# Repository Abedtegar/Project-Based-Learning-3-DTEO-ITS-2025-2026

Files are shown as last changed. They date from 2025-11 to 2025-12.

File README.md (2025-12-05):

# SISTEM KONTROL SEDERHANA

## Eskalator Mini Motor DC dengan Kendali ESP32 menggunakan Kontrol PID

---

### 👥 Tim Pengembang

| No | Nama | NRP |
|---|---|---|
| 1 | Abednego Tegar Imanto | 2040241044 |
| 2 | Muhammad Rifky Naufal | 2040241032 |
| 3 | Piet Avin Dutabuana | 2040241051 |
| 4 | Dhonan Rachma Dio Putra | 2040241086 |
| 5 | Luna Aulia Afifah | 2040241092 |
| 6 | Saniiyah Rif'atunnisa' | 2040241099 |

**Proyek**: CBL Semester 3 - Departemen Teknik Elektro Otomasi  
**Institusi**: Institut Teknologi Sepuluh Nopember (ITS)  
**Tahun**: 2024/2025

---

## 📋 Deskripsi Proyek

Repository ini berisi seluruh program untuk sistem kontrol escalator berbasis ESP32/ESP8266 yang dikembangkan untuk proyek CBL Semester 3. Sistem ini menggunakan arsitektur terdistribusi dengan dua board utama yang berkomunikasi melalui protokol ESP-NOW untuk kontrol motor DC (escalator) dan motor AC dengan kontrol PID real-time.

## Struktur Project

```
Program/
├── ambil_data_encoder/     # Program testing & kalibrasi encoder motor DC
├── Interface_Board/        # HMI control panel dengan LCD TFT dan encoder
├── Plant_Board/           # Controller utama motor DC/AC dengan PID
├── Tes_Interface_esp32/   # Testing dan debugging interface
├── Design_3D/             # Model 3D box, eskalator, dan interface
├── PCB_Board/             # Desain PCB Interface Board & Plant Board
└── DOKUMEN/               # Data pengukuran motor AC (CSV)
```

## Deskripsi Project

### 1. Interface_Board (HMI - Human Machine Interface)
Board interface sebagai panel kontrol dan monitoring sistem. Menggunakan LCD TFT dengan menu grafis interaktif, rotary encoder sebagai input, dan komunikasi wireless ESP-NOW.

**Platform**: ESP32 / ESP8266  
**Fitur Utama**:

#### A. Sistem Menu Navigasi
- **Main Menu**: 3 menu utama (Escalator, Motor AC, WiFi Status)
- **Escalator Menu**: 
  - Graph Mode: Real-time oscilloscope-style graph dengan buffer 100 sample
  - Control Mode: Setting PID parameters, setpoint, direction, run/stop
- **Motor AC Menu**: 
  - Graph Mode: Real-time monitoring RPM AC motor
  - Control Mode: Konfigurasi PID AC, setpoint, dan control mode
- **WiFi Menu**: Status monitoring ESP-NOW dan WiFi connection

#### B. Sistem Input (Rotary Encoder)
- **Single Click**: Select/Enter menu atau toggle edit mode
- **Double Click**: Toggle encoder direction (UP/DOWN) atau quick motor run/stop di graph mode
- **Long Press (>1 detik)**: Back/Exit ke menu sebelumnya
- **Scroll**: Navigasi menu atau edit nilai parameter (debounced)
- **Encoder Mode**: Toggle UP (increment) atau DOWN (decrement) untuk kontrol yang lebih presisi

#### C. Display & Visualisasi (LCD ST7735 128x160)
- **Grafik Real-time**: 
  - Incremental pixel rendering (oscilloscope-style) untuk efisiensi
  - Buffer 116 pixel dengan mapping ke 100 sample
  - Setpoint line (red dashed)
  - Auto-scaling untuk DC (0-115 RPM) dan AC (0-1500 RPM)
  - Error calculation dan percentage display
- **Control Screen**: Live editing PID parameters (Kp, Ki, Kd, Setpoint)
- **Status Indicators**: Motor state (RUN/STOP), connection status
- **Splash Screen**: Startup animation dengan versi info

#### D. Komunikasi ESP-NOW
- **TX Messages**: Command dan parameter ke Plant Board
  - Motor control (DC/AC run/stop)
  - PID parameters (Kp, Ki, Kd, Setpoint)
  - Direction control (FWD/REV)
  - Speed request flags
- **RX Messages**: Data monitoring dari Plant Board
  - Real-time RPM (DC & AC)
  - Timestamp untuk sinkronisasi
  - PID parameters confirmation
  - Motor status feedback
- **Tagged Float Protocol**: 8-byte frame (4-byte typeID + 4-byte float value)

#### E. Sistem Monitoring PID
- **Response Analysis**: Buffer 500 sample untuk analisis settling time
- **Timestamp Tracking**: 100-entry circular buffer untuk grid waktu
- **Error Metrics**: Perhitungan average error 50 sample terakhir
- **Percentage Error**: Error relatif terhadap setpoint

### 2. Plant_Board (Controller & Actuator)
Controller utama yang menjalankan algoritma PID dan mengendalikan motor DC (escalator) dan motor AC. Board ini bertindak sebagai "otak" sistem dengan kontrol loop tertutup.

**Platform**: ESP32  
**Fitur Utama**:

#### A. Kontrol Motor DC (Escalator)
- **PWM Control**: 12-bit resolution (0-4095), 500 Hz frequency
- **Direction Control**: Pin dedicated untuk CW/CCW
- **Encoder Quadrature**: Channel A (primary) dengan interrupt FALLING edge
- **PPR**: 14 pulses per revolution
- **Sampling Rate**: 50ms (20 Hz) dengan hardware timer
- **Speed Calculation**: RPM = (pulseCount × 60000) / (interval × PPR)
- **Gearbox Ratio**: 200:1 untuk konversi motor RPM ke output RPM

#### B. Kontrol Motor AC
- **PWM DAC Control**: 12-bit PWM untuk DAC, 8-bit output (0-255)
- **Analog Encoder**: ADC 10-bit pada GPIO32
- **Kalman Filter**: 
  - Process noise: 0.01 (tunable)
  - Measurement noise: 3.0 (tunable)
  - Mengurangi noise sensor analog untuk pembacaan RPM yang stabil
- **Scaling Factor**: 2.304147465 untuk konversi ADC ke RPM
- **Voltage Select**: Pin control untuk pemilihan tegangan DAC
- **Sampling Rate**: 10ms (100 Hz)

#### C. PID Controller (Dual Independent)
- **DC PID**:
  - Default: Kp=1.5, Ki=0.1, Kd=0.05
  - Anti-Windup: Integral clamping (±1000)
  - Anti-Stall: Minimum PWM 800 untuk mencegah motor mati
  - Output saturation: ±4095 (12-bit PWM)
  - Sample time: 50ms (sesuai encoder timer)
  
- **AC PID**:
  - Default: Kp=2.0, Ki=0.08, Kd=0.04
  - Anti-Windup: Integral clamping (±1000)
  - Anti-Stall: Minimum PWM 800
  - Output saturation: 0-255 (8-bit DAC)
  - Sample time: 10ms (sesuai encoder timer)
  
- **PID Algorithm**:
  ```
  error = setpoint - measured
  P = Kp × error
  I = Ki × Σ(error × dt)    [with clamping]
  D = Kd × (error - prev_error) / dt
  output = P + I + D        [with saturation & anti-stall]
  ```

#### D. Data Persistence (NVS Storage)
- **Preferences Library**: Non-Volatile Storage di flash ESP32
- **Stored Parameters**:
  - DC PID: Kp, Ki, Kd, Setpoint, Direction
  - AC PID: Kp, Ki, Kd, Setpoint, Voltage
- **Auto-Load**: Parameter dimuat saat startup
- **Auto-Save**: Parameter disimpan saat diterima dari Interface Board
- **Reset Function**: Clear all NVS dan restart

#### E. LED Indicators (4 LED)
- **LED_WIFI (GPIO21)**: Status komunikasi ESP-NOW (ON saat TX success)
- **LED_PID (GPIO19)**: Mode PID aktif/non-aktif
- **LED_DC_CONTROL (GPIO18)**: Motor DC running
- **LED_AC_CONTROL (GPIO5)**: Motor AC running

#### F. Hardware Timer System
- **Timer 0**: DC encoder sampling (50ms)
- **Timer 1**: AC encoder sampling (10ms)
- **ISR Safety**: portENTER_CRITICAL / portEXIT_CRITICAL untuk shared variables
- **Brownout Disable**: WRITE_PERI_REG untuk stabilitas saat PWM tinggi

#### G. Komunikasi ESP-NOW
- **WiFi Mode**: STA (Station) mode
- **MAC Filtering**: Hanya menerima dari Interface Board MAC yang terdaftar
- **Callback Functions**:
  - OnDataSent: Konfirmasi transmisi (LED feedback)
  - receiveData: Parse command dan update parameter
- **Message Types**: 32 jenis message ID (DC/AC control, PID params, etc.)

## Arsitektur Sistem

### Diagram Blok Komunikasi

```
┌──────────────────────────────────────────────────────────────────────┐
│                         INTERFACE BOARD                              │
│                       (ESP32/ESP8266 - HMI)                          │
├──────────────────────────────────────────────────────────────────────┤
│  ┌─────────────┐    ┌──────────────┐    ┌──────────────┐             │
│  │  LCD ST7735 │    │    Rotary    │    │   ESP-NOW    │             │
│  │  128x160px  │◄───┤   Encoder    │◄───┤   Protocol   │             │
│  │  Real-time  │    │  + Button    │    │   (Tagged    │             │
│  │   Graphs    │    │ (Scroll/Clk) │    │    Float)    │             │
│  └─────────────┘    └──────────────┘    └───────┬──────┘             │
│                                                 │                    │
│  Features:                                      │                    │
│  - Menu Navigation (3 levels)                   │ TX: Commands       │
│  - PID Parameter Editor                         │     Parameters     │
│  - Oscilloscope-style Graph                     │     Setpoints      │
│  - Motor Control (Run/Stop)                     │                    │
│  - Real-time Monitoring                         │ RX: RPM Data       │
└─────────────────────────────────────────────────┼────────────────────┘
                                                  │
                              ESP-NOW Wireless    │
                            (2.4GHz, <250 bytes)  │
                                                  │
┌─────────────────────────────────────────────────┼──────────────────────┐
│                          PLANT BOARD            │                      │
│                    (ESP32 - Controller)         │                      │
├─────────────────────────────────────────────────┴──────────────────────┤
│  ┌──────────────┐    ┌──────────────┐    ┌──────────────┐              │
│  │   ESP-NOW    │    │   Dual PID   │    │   Hardware   │              │
│  │   Protocol   ├───►│  Controller  ├───►│    Timers    │              │
│  │   Receiver   │    │   (DC & AC)  │    │  (50ms/10ms) │              │
│  └──────────────┘    └──────────────┘    └───────┬──────┘              │
│                                                  │                     │
│                      ┌───────────────────────────┴────────────┐        │
│                      │                                        │        │
│              ┌───────▼─────────┐                    ┌─────────▼───────┐│
│              │  DC MOTOR       │                    │   AC MOTOR      ││
│              │  + Encoder      │                    │   + Encoder     ││
│              ├─────────────────┤                    ├─────────────────┤│
│              │ - PWM 12-bit    │                    │ - PWM DAC 8-bit ││
│              │ - Quadrature    │                    │ - Analog ADC    ││
│              │ - 14 PPR        │                    │ - Kalman Filter ││
│              │ - Gearbox 200:1 │                    │ - 0-1500 RPM    ││
│              │ - 0-115 RPM out │                    │ - Voltage Sel   ││
│              │ - Direction Ctl │                    │                 ││
│              └─────────────────┘                    └─────────────────┘│
│                                                                        │
│  ┌──────────────┐    ┌──────────────┐    ┌──────────────┐              │
│  │  NVS Storage │    │  4x LED      │    │  Brownout    │              │
│  │  (PID Params)│    │  Indicators  │    │  Disable     │              │
│  └──────────────┘    └──────────────┘    └──────────────┘              │
│                                                                        │
│  Features:                                                             │
│  - Dual Independent PID (DC 50ms, AC 10ms)                             │
│  - Anti-Windup & Anti-Stall                                            │
│  - Kalman Filter untuk AC encoder                                      │
│  - Parameter Persistence (NVS Flash)                                   │
│  - Real-time Data Transmission                                         │
└────────────────────────────────────────────────────────────────────────┘
```

### Alur Komunikasi Data

**1. Startup Sequence:**
```
Plant Board:
1. Load PID parameters dari NVS Storage
2. Initialize LED indicators
3. Setup ESP-NOW (WiFi STA mode)
4. Initialize encoders (DC & AC)
5. Start PWM timers
6. Start hardware timers (50ms DC, 10ms AC)
7. Send parameter confirmation ke Interface

Interface Board:
1. Initialize LCD ST7735
2. Initialize rotary encoder + button
3. Setup ESP-NOW
4. Show splash screen (2 detik)
5. Load main menu
6. Request Plant Board restart (sync)
```

**2. Real-time Control Loop:**
```
Interface Board (Main Loop ~10ms):
1. Read encoder position (interrupt-based)
2. Detect button clicks (single/double/long)
3. Update menu state (navigate/edit/select)
4. Send commands via ESP-NOW (jika ada perubahan)
5. Receive RPM data dari Plant
6. Update display (incremental rendering)

Plant Board (Timer ISR):
DC Timer (50ms):
  1. Calculate pulse count
  2. Compute RPM = (pulseCount × 60000) / (50 × 14)
  3. Apply gearbox ratio (÷200)
  4. Run PID if enabled
  5. Set PWM output
  6. Send data via ESP-NOW

AC Timer (10ms):
  1. Read ADC value
  2. Apply Kalman filter
  3. Compute RPM = ADC × 2.304147465
  4. Run PID if enabled
  5. Set DAC output
  6. Send data via ESP-NOW
```

**3. PID Control Flow:**
```
┌─────────────────────────────────────────────────────────────┐
│                     PID CONTROL LOOP                        │
├─────────────────────────────────────────────────────────────┤
│  1. Read Setpoint (dari Interface Board)                    │
│  2. Read Current RPM (dari Encoder)                         │
│  3. Calculate Error = Setpoint - Current                    │
│  4. Calculate P = Kp × Error                                │
│  5. Calculate I = Ki × Σ(Error × dt)  [Anti-Windup]         │
│  6. Calculate D = Kd × (Error - PrevError) / dt             │
│  7. Output = P + I + D                                      │
│  8. Apply Saturation (0-4095 DC, 0-255 AC)                  │
│  9. Apply Anti-Stall (minimum PWM 800)                      │
│ 10. Write to PWM/DAC                                        │
│ 11. Store PrevError                                         │
│ 12. Send RPM & Error ke Interface                           │
└─────────────────────────────────────────────────────────────┘
```

**4. ESP-NOW Message Protocol:**
```
Frame Format: [TypeID: 4 bytes][Value: 4 bytes] = 8 bytes total

Message Types (Interface → Plant):
- MSG_DC_KP (11): Kp untuk DC PID
- MSG_DC_KI (12): Ki untuk DC PID
- MSG_DC_KD (13): Kd untuk DC PID
- MSG_DC_Setpoint (14): Target RPM DC motor
- MSG_DC_Control (15): Run/Stop DC motor (1/0)
- MSG_DC_Direction (16): Direction FWD/REV (0/1)
- MSG_AC_KP (21): Kp untuk AC PID
- MSG_AC_KI (22): Ki untuk AC PID
- MSG_AC_KD (23): Kd untuk AC PID
- MSG_AC_Setpoint (24): Target RPM AC motor
- MSG_AC_Control (25): Run/Stop AC motor (1/0)
- MSG_AC_Voltage (26): Voltage selection
- MSG_PID_MODE (30): Enable/Disable PID (1/0)
- MSG_SPD_REQUEST (31): Request speed data (1=DC, 2=AC, 0=off)
- ESP_RESTART (100): Restart Plant Board

Message Types (Plant → Interface):
- MSG_DC_SPEED (10): Current RPM DC motor
- MSG_AC_SPEED (20): Current RPM AC motor
- MSG_TIMESTAMP (32): Timestamp untuk sinkronisasi
- MSG_DC_KP/KI/KD: Confirmation parameter diterima
- MSG_AC_KP/KI/KD: Confirmation parameter diterima
```

## Requirements

### Hardware
- ESP32 Development Board 
- ESP8266 NodeMCU (opsional, untuk Interface)
- LCD ST7735 TFT Display (128x160)
- Rotary Encoder dengan push button
- Motor DC dengan encoder
- Motor AC (opsional)
- Motor Driver

### Software
- [PlatformIO](https://platformio.org/)
- VS Code dengan PlatformIO extension
- Driver CH340/CP2102 (untuk ESP32/ESP8266)

### Libraries
- Adafruit GFX Library
- Adafruit ST7735 Library
- ESP-NOW (built-in)
- WiFi (built-in)

## Quick Start

### 1. Install PlatformIO
```bash
# Install PlatformIO CLI atau gunakan VS Code extension
pip install platformio
```

### 2. Clone/Download Repository
```bash
cd "d:\Kuliah\ITS\SMT3\CBL\Program"
```

### 3. Build & Upload

#### Plant Board (Upload pertama)
```bash
cd Plant_Board
platformio run --target upload
platformio device monitor
# Catat MAC address yang muncul di serial monitor
```

#### Interface Board
```bash
cd Interface_Board
# Edit include/PinConfig.h, sesuaikan PLANT_MAC dengan MAC Plant Board
platformio run --target upload
platformio device monitor
```

## Konfigurasi Detail

### 1. Plant Board Configuration

**File: `Plant_Board/include/PlantConfig.h`**

#### A. Pin Configuration

```cpp
// DC Motor Control
#define MOTOR_PWM_PIN 13        // PWM output ke motor driver
#define MOTOR_DIR_PIN 23        // Direction control (CW/CCW)
#define PWM_CHANNEL 0           // LEDC channel
#define PWM_FREQ 500            // 500 Hz PWM frequency
#define PWM_RESOLUTION 12       // 12-bit (0-4095)

// DC Motor Encoder
#define ENCODER_A_PIN 34        // Channel A (primary interrupt)
#define ENCODER_B_PIN 35        // Channel B (direction detection)
#define PPR 14                  // Pulses Per Revolution
#define DCREAD_INTERVAL 50      // Sampling interval 50ms

// AC Motor Control
#define AC_DAC1_PIN 25          // DAC output 1
#define AC_DAC2_PIN 26          // DAC output 2
#define AC_DAC_SOURCE_PIN 27    // Source selection
#define AC_DAC_VOLTAGE_SELECT_PIN 12  // Voltage level selection
#define ACPWM_CHANNEL 1         // LEDC channel untuk DAC
#define ACPWM_FREQ 500          // PWM frequency
#define ACPWM_RESOLUTION 12     // 12-bit resolution

// AC Motor Encoder
#define AC_ENCODER_PIN 32       // Analog input (ADC)
#define ACREAD_INTERVAL 10      // Sampling interval 10ms
#define AC_READ_SCALING_FACTOR 2.304147465f  // ADC to RPM conversion

// LED Indicators
#define LED_WIFI 21             // ESP-NOW communication status
#define LED_PID 19              // PID mode active
#define LED_DC_CONTROL 18       // DC motor running
#define LED_AC_CONTROL 5        // AC motor running
```

#### B. Network Configuration

```cpp
// MAC Address Interface Board (dapatkan dari Serial Monitor Interface)
static const uint8_t INTERFACE_MAC[] = {
    0x50, 0x02, 0x91, 0x78, 0x72, 0xA7  // SESUAIKAN DENGAN MAC ANDA
};

// Data transmission interval
#define DATA_SEND_INTERVAL 1000  // Kirim data setiap 1000ms
```

#### C. PID Tuning Parameters

**File: `Plant_Board/src/PID.cpp`**

```cpp
// DC Motor PID (Escalator)
volatile float DCkP = 1.5f;      // Proportional gain
volatile float DCkI = 0.1f;      // Integral gain
volatile float DCkD = 0.05f;     // Derivative gain
volatile float DCsetpoint = 50.0f;  // Target RPM (output shaft)

// AC Motor PID
volatile float ACkP = 2.0f;      // Proportional gain
volatile float ACkI = 0.08f;     // Integral gain
volatile float ACkD = 0.04f;     // Derivative gain
volatile float ACsetpoint = 0.0f;   // Target RPM

// Anti-Windup Limits
#define DC_INTEGRAL_MAX 1000.0   // Max integral accumulation
#define DC_INTEGRAL_MIN -1000.0
#define AC_INTEGRAL_MAX 1000.0
#define AC_INTEGRAL_MIN -1000.0

// Anti-Stall Minimum PWM
#define DC_PWM_MIN 800.0f        // Minimum PWM untuk mencegah stall
#define AC_PWM_MIN 800.0f
```

#### D. Kalman Filter Tuning (AC Motor)

**File: `Plant_Board/src/Plant.cpp`**

```cpp
// Kalman Filter Parameters
float AC_process_noise = 0.01;   // Process noise covariance (Q)
float AC_error_measure = 4.0;    // Measurement noise covariance (R)

// Adjust di setup():
ACsetKalmanParams(0.01, 3.0);   // (process_noise, measure_noise)
// - Turunkan process_noise untuk response lebih lambat tapi smooth
// - Turunkan measure_noise jika sensor akurat
```

### 2. Interface Board Configuration

**File: `Interface_Board/include/PinConfig.h`**

#### A. Pin Configuration (ESP32)

```cpp
// LCD ST7735 (SPI)
#define TFT_CS 15               // Chip Select
#define TFT_RST 4               // Reset
#define TFT_DC 5                // Data/Command
// Hardware SPI: MOSI=23, SCK=18

// Rotary Encoder
#define ENCODER_CLK 27          // Clock (Channel A) - NOT USED in interrupt
#define ENCODER_DT 26           // Data (Channel B) - PRIMARY interrupt
#define ENCODER_SW 25           // Switch button (polling)
```

#### B. Pin Configuration (ESP8266)

```cpp
// LCD ST7735 (SPI)
#define TFT_CS 15               // GPIO15
#define TFT_RST 4               // GPIO4
#define TFT_DC 5                // GPIO5
// Hardware SPI: MOSI=GPIO13, SCK=GPIO14

// Rotary Encoder
#define ENCODER_CLK 12          // GPIO12
#define ENCODER_DT 2            // GPIO2 - PRIMARY interrupt
#define ENCODER_SW 16           // GPIO16
```

#### C. Network Configuration

```cpp
// WiFi AP (Optional - currently not used)
#define WIFI_AP_SSID "GameBoard_AP"
#define WIFI_AP_PASSWORD "12345678"

// MAC Address Plant Board (dapatkan dari Serial Monitor Plant)
static const uint8_t PLANT_MAC[6] = {
    0x7C, 0x9E, 0xBD, 0x48, 0x85, 0xB4  // SESUAIKAN DENGAN MAC ANDA
};
```

#### D. Display Configuration

**File: `Interface_Board/src/src/ControlMenuSystem_simple.cpp`**

```cpp
// Graph Scaling
constexpr float ESC_GRAPH_MAX = 115.0f;   // Max RPM DC (output shaft)
constexpr float AC_GRAPH_MAX = 1500.0f;   // Max RPM AC

// History Buffer
#define MAX_SAMPLES 100          // Jumlah sample dalam buffer
#define GRAPH_WIDTH 116          // Pixel width grafik

// Timing
#define DEBOUNCE_TIME 50         // Button debounce (ms)
#define LONG_PRESS_TIME 1000     // Long press detection (ms)
#define DOUBLE_CLICK_TIME 400    // Double click window (ms)
```

### 3. Cara Mendapatkan MAC Address

#### Plant Board:

```bash
cd Plant_Board
platformio device monitor -b 115200
```

Output akan menampilkan:
```
=== PLANT BOARD STARTUP ===
ESP-NOW MAC Address: 7C:9E:BD:48:85:B4
```

Salin MAC address ini ke `Interface_Board/include/PinConfig.h`

#### Interface Board:

```bash
cd Interface_Board
platformio device monitor -b 115200
```

Output akan menampilkan MAC address ESP8266/ESP32.
Salin ke `Plant_Board/include/PlantConfig.h`

### 4. PID Tuning Guide

#### Metode Ziegler-Nichols (Manual Tuning)

1. **Set Ki = 0, Kd = 0**
2. **Naikkan Kp** hingga sistem oscillate (bergetar stabil)
3. **Catat Ku (Kp critical)** dan **Tu (periode oscillasi)**
4. **Hitung parameter**:
   - Kp = 0.6 × Ku
   - Ki = 1.2 × Ku / Tu
   - Kd = 0.075 × Ku × Tu

#### Fine Tuning:

**Kp (Proportional)**:
- Terlalu kecil: Response lambat, steady-state error besar
- Terlalu besar: Overshoot, oscillation
- Optimal: Response cepat tanpa overshoot berlebih

**Ki (Integral)**:
- Terlalu kecil: Steady-state error tidak hilang
- Terlalu besar: Integral windup, slow settling
- Optimal: Eliminasi steady-state error dalam waktu wajar

**Kd (Derivative)**:
- Terlalu kecil: Overshoot besar
- Terlalu besar: Noise amplification, sistem tidak stabil
- Optimal: Damping overshoot tanpa noise berlebih

#### Tuning Melalui Interface:

1. Pilih menu **Escalator** atau **Motor AC**
2. Pilih **Control** (single click di graph mode)
3. Navigate ke parameter yang ingin diedit
4. Single click untuk enter edit mode
5. Putar encoder untuk adjust nilai
6. Single click lagi untuk save & transmit ke Plant

## Testing

### Test Encoder
```bash
cd Tes_Interface_esp32
platformio run --target upload
platformio device monitor
# Putar encoder dan lihat output
```

### Test Komunikasi ESP-NOW
1. Upload Plant_Board
2. Upload Interface_Board
3. Monitor serial pada kedua board
4. Cek status ESP-NOW di menu Interface

## Troubleshooting

### 1. ESP-NOW Tidak Terkoneksi

**Gejala:**
- LED_WIFI pada Plant Board tidak menyala
- Status ESP-NOW di menu WiFi menampilkan "FAIL"
- Tidak ada data RPM yang diterima Interface Board

**Solusi:**

A. **Verifikasi MAC Address**
```bash
# Plant Board
platformio device monitor -b 115200
# Lihat output: "ESP-NOW MAC Address: XX:XX:XX:XX:XX:XX"

# Pastikan MAC ini sama dengan yang di Interface_Board/include/PinConfig.h
```

B. **Cek WiFi Mode**
```cpp
// Plant Board: WiFi.mode(WIFI_STA) - harus STA mode
// Interface Board: WiFi.mode(WIFI_STA) atau WIFI_AP_STA
```

C. **Restart Sequence**
1. Upload Plant Board → tunggu hingga "ESP-NOW siap"
2. Upload Interface Board → auto send restart command
3. Monitor Serial kedua board untuk konfirmasi

D. **Cek Channel WiFi**
- ESP-NOW harus di channel yang sama (default: 0 = auto)
- Jika ada WiFi router nearby, bisa conflict

**Debug Command:**
```cpp
// Tambahkan di Plant_Board/src/PlantESPNow.cpp
Serial.print("Peer add result: ");
Serial.println(esp_now_add_peer(&peerInfo));  // Harus return 0 (ESP_OK)
```

### 2. Encoder Tidak Terbaca / Count Tidak Akurat

**Gejala:**
- RPM selalu 0 atau tidak berubah
- Count encoder tidak increment saat motor berputar
- Arah putaran terbalik

**Solusi:**

A. **Cek Koneksi Hardware**
```
Encoder Pin:
- Channel A (CLK) → ESP32 GPIO34/35 (input only pins)
- Channel B (DT)  → ESP32 GPIO35/34
- VCC → 3.3V (JANGAN 5V!)
- GND → GND
- Pull-up resistor: 10kΩ ke VCC (jika encoder tidak ada internal pull-up)
```

B. **Test Encoder Standalone**
```bash
cd ambil_data_encoder
platformio run --target upload
platformio device monitor

# Putar encoder manual, lihat output count
```

C. **Verifikasi Interrupt**
```cpp
// Interface Board: Hanya attach ENCODER_DT dengan FALLING edge
attachInterrupt(digitalPinToInterrupt(ENCODER_DT), DChandleEncoder, FALLING);
// JANGAN attach CLK untuk mencegah double trigger

// Plant Board: Attach ENCODER_A_PIN dengan CHANGE
attachInterrupt(digitalPinToInterrupt(ENCODER_A_PIN), DChandleEncoderA, CHANGE);
```

D. **Direction Terbalik**
- Swap Channel A dan B di konfigurasi
- Atau toggle `DCDirection` di logika

E. **Noise / Bouncing**
- Tambahkan capacitor 100nF antara setiap pin encoder dan GND
- Kurangi panjang kabel encoder
- Gunakan shielded cable untuk encoder

### 3. LCD Tidak Menyala / Blank Screen

**Gejala:**
- LCD putih atau blank setelah power on
- Backlight nyala tapi tidak ada gambar
- Splash screen tidak muncul

**Solusi:**

A. **Cek Koneksi SPI**
```
LCD ST7735 Pin → ESP32/ESP8266:
- VCC → 3.3V atau 5V (sesuai spesifikasi LCD)
- GND → GND
- CS  → GPIO15 (TFT_CS)
- RST → GPIO4 (TFT_RST)
- DC  → GPIO5 (TFT_DC)
- MOSI → GPIO23 (ESP32) atau GPIO13 (ESP8266)
- SCK → GPIO18 (ESP32) atau GPIO14 (ESP8266)
- LED → 3.3V (backlight)
```

B. **Test Koneksi dengan Multimeter**
- Cek continuity dari ESP pin ke LCD pin
- Cek tegangan VCC = 3.3V atau 5V
- Cek GND tidak short dengan VCC

C. **Manual Reset LCD**
```cpp
// Tambahkan di setup() sebelum tft.initR()
digitalWrite(TFT_RST, LOW);
delay(100);
digitalWrite(TFT_RST, HIGH);
delay(100);
```

D. **Cek Inisialisasi LCD**
```cpp
// Ganti INITR_BLACKTAB dengan yang lain jika blank
tft.initR(INITR_BLACKTAB);   // Coba: INITR_GREENTAB, INITR_REDTAB
tft.setRotation(0);           // Coba: 0, 1, 2, 3
```

E. **Power Supply Tidak Cukup**
- LCD butuh ~50-100mA saat backlight ON
- Gunakan power supply minimal 500mA
- Jangan powered dari USB komputer yang lemah

### 4. PID Tidak Stabil / Oscillating

**Gejala:**
- Motor bergetar (hunting)
- RPM overshoot berlebihan
- Tidak bisa mencapai setpoint

**Solusi:**

A. **Tuning PID Terlalu Agresif**
```cpp
// Mulai dari konservatif:
DCkP = 0.5;   // Kurangi Kp hingga oscillation hilang
DCkI = 0.01;  // Mulai dari Ki sangat kecil
DCkD = 0.0;   // Set Kd = 0 dulu

// Naikkan Kp bertahap hingga response cepat tapi tidak oscillate
// Tambahkan Ki untuk eliminasi steady-state error
// Tambahkan Kd jika masih overshoot
```

B. **Anti-Windup Tidak Efektif**
```cpp
// Pastikan integral clamping aktif
if (DCintegralSum > DC_INTEGRAL_MAX)
    DCintegralSum = DC_INTEGRAL_MAX;
else if (DCintegralSum < DC_INTEGRAL_MIN)
    DCintegralSum = DC_INTEGRAL_MIN;
```

C. **Sampling Rate Terlalu Lambat**
- DC: 50ms (20 Hz) - OK untuk most applications
- AC: 10ms (100 Hz) - Bisa turunkan jika masih oscillate
- Semakin cepat motor, perlu sampling rate lebih tinggi

D. **Motor Stall (Anti-Stall Aktif Terlalu Sering)**
```cpp
// Turunkan DC_PWM_MIN jika motor sering "jump"
#define DC_PWM_MIN 600.0f  // Default 800, coba turunkan
```

E. **Mechanical Load Berubah**
- PID tuning valid untuk specific load
- Jika load berubah drastis, perlu re-tune atau adaptive PID

### 5. Motor Tidak Berputar / Stuck

**Gejala:**
- PWM output sudah benar tapi motor diam
- Motor bergetar tapi tidak rotate
- Motor berputar hanya di PWM tinggi

**Solusi:**

A. **Cek Motor Driver**
```
Driver Pin:
- PWM signal OK? (cek dengan oscilloscope atau LED)
- Direction signal OK?
- Enable pin HIGH?
- Power supply driver cukup? (minimal 1A untuk motor kecil)
```

B. **Cek Power Supply Motor**
- Tegangan motor sesuai rating (6V, 12V, 24V, etc.)
- Current rating cukup (motor butuh 2-5A saat start)
- Cek voltage drop saat motor start

C. **PWM Frequency Terlalu Rendah/Tinggi**
```cpp
// Coba adjust PWM frequency
#define PWM_FREQ 500   // Default, coba 1000 atau 20000
```

D. **Dead Zone / Starting Torque**
```cpp
// Motor perlu minimum PWM untuk overcome starting torque
#define DC_PWM_MIN 1000.0f  // Naikkan dari 800
```

E. **Motor Rusak / Bearing Macet**
- Coba putar motor manual → harus smooth
- Cek dengan multimeter: resistance coil motor normal

### 6. Data Serial Monitor Corrupt / Tidak Terbaca

**Gejala:**
- Character acak di serial monitor
- Data tidak lengkap atau putus-putus

**Solusi:**

A. **Cek Baud Rate**
```bash
# Pastikan 115200 di semua board
platformio device monitor -b 115200
```

B. **Driver USB-Serial**
- Install driver CH340 atau CP2102
- Windows: Device Manager → Ports → update driver
- Linux: `sudo usermod -a -G dialout $USER` (logout-login)

C. **Kabel USB Rusak**
- Ganti dengan kabel USB yang bagus (data + power)
- Jangan gunakan charging-only cable

D. **Buffer Overflow**
```cpp
// Kurangi Serial.print() di dalam ISR
// Gunakan flag dan print di main loop
```

### 7. ESP32 Brownout / Restart Terus

**Gejala:**
- ESP32 restart sendiri saat motor start
- Serial output: "Brownout detector was triggered"

**Solusi:**

A. **Disable Brownout Detector** (temporary)
```cpp
// Di setup() Plant_Board
#include "soc/soc.h"
#include "soc/rtc_cntl_reg.h"
WRITE_PERI_REG(RTC_CNTL_BROWN_OUT_REG, 0);
```

B. **Power Supply Tidak Cukup** (root cause)
- ESP32 butuh minimal 500mA
- Motor + ESP32 total bisa 3-5A
- JANGAN powered motor dari ESP32 VCC
- Gunakan power supply terpisah untuk motor dan ESP32
- Common ground antara power supply motor dan ESP32

C. **Decoupling Capacitor**
- Tambahkan 100µF capacitor di VCC ESP32
- Tambahkan 0.1µF ceramic capacitor di setiap VCC pin

### 8. Kalman Filter AC Motor Tidak Smooth

**Gejala:**
- RPM AC masih noisy
- Filter tidak efektif

**Solusi:**

A. **Tuning Parameter Kalman**
```cpp
// Naikkan measurement noise jika sensor sangat noisy
ACsetKalmanParams(0.01, 5.0);  // process_noise, measure_noise

// Turunkan process noise untuk smoother tapi slower response
ACsetKalmanParams(0.005, 3.0);
```

B. **Moving Average Tambahan**
```cpp
// Tambahkan simple moving average sebelum Kalman
#define MA_SIZE 5
float ma_buffer[MA_SIZE];
float ma_sum = 0;
int ma_index = 0;

// Update buffer
ma_sum -= ma_buffer[ma_index];
ma_buffer[ma_index] = raw_rpm;
ma_sum += raw_rpm;
ma_index = (ma_index + 1) % MA_SIZE;
float filtered = ma_sum / MA_SIZE;
```

C. **Hardware Filter**
- Tambahkan RC filter di output sensor analog
- R = 10kΩ, C = 100nF → cutoff ~160 Hz

## Serial Monitor

Baud rate untuk semua project: **115200**

```bash
# Monitor dengan PlatformIO
platformio device monitor -b 115200

# Atau gunakan serial monitor lain
# Arduino IDE, PuTTY, dll.
```

## Advanced Features & Technical Details

### 1. Real-time Graph Rendering (Oscilloscope-Style)

Interface Board menggunakan teknik **incremental pixel rendering** untuk update grafik secara efisien tanpa full redraw.

**Algoritma:**
```cpp
// Buffer Y-position untuk setiap kolom pixel (116 kolom)
static int escGraphY[116];

// Setiap data baru masuk:
1. Shift buffer kanan ke kiri (escGraphY[i] = escGraphY[i-1])
2. Hapus pixel lama di posisi yang berubah
3. Gambar pixel baru di posisi baru
4. Update setpoint line (red dashed)
5. Update metrics (speed, error, percent error)

// Hasil: Smooth scrolling graph tanpa flicker
```

**Metrics Calculation:**
- **Current Speed**: Nilai RPM terbaru dari Plant Board
- **Setpoint**: Target RPM (red line)
- **Error**: `Current - Setpoint`
- **Percent Error**: Average absolute error 50 sample terakhir / setpoint × 100%

### 2. Encoder Quadrature Decoding

**Plant Board (DC Motor):**
```cpp
// Single-edge interrupt pada Channel A dengan pembacaan Channel B
void IRAM_ATTR DChandleEncoderA() {
    int stateA = digitalRead(ENCODER_A_PIN);
    int stateB = digitalRead(ENCODER_B_PIN);
    
    if (stateA == HIGH) {
        if (stateB == LOW) DCencoder++;  // CW rotation
        else DCencoder--;                 // CCW rotation
    } else {
        if (stateB == HIGH) DCencoder++;
        else DCencoder--;
    }
}

// Keuntungan: 
// - Deteksi arah otomatis
// - Resolution 4x (jika attach kedua channel)
// - Debouncing hardware dengan interrupt CHANGE
```

**Interface Board (Rotary Encoder):**
```cpp
// Mode-based increment/decrement
if (encoderMode == ENCODER_UP) {
    DCencoder++;   // Increment mode
} else {
    DCencoder--;   // Decrement mode
}

// Keuntungan:
// - User bisa toggle arah scroll
// - Lebih intuitif untuk menu navigation
// - Single interrupt pada DT pin (less noise)
```

### 3. ESP-NOW Protocol Efficiency

**Frame Structure:**
```
Byte 0-3: TypeID (int32_t)  → Identifier jenis data
Byte 4-7: Value (float)      → Payload data

Total: 8 bytes per message
```

**Keuntungan:**
- **Compact**: Hanya 8 bytes (vs JSON ~50-100 bytes)
- **Fast**: Parsing langsung dengan memcpy, no string parsing
- **Type-safe**: TypeID mencegah misinterpretation
- **Scalable**: Mudah tambah message type baru

**Latency Analysis:**
- ESP-NOW TX time: ~1-2ms
- Processing time: <1ms
- Total latency: <5ms (real-time control)

### 4. NVS Storage Implementation

**Persistence Layer:**
```cpp
Preferences preferences;

// Save (Plant Board)
preferences.begin("plant_config", false);  // namespace
preferences.putFloat("dc_kp", DCkP);
preferences.putFloat("dc_ki", DCkI);
// ... dst

// Load (Plant Board startup)
DCkP = preferences.getFloat("dc_kp", 1.5f);  // default 1.5
DCkI = preferences.getFloat("dc_ki", 0.1f);
```

**Benefits:**
- **Non-volatile**: Parameter tersimpan meski power off
- **Fast**: Flash read <1ms
- **Reliable**: Wear leveling otomatis oleh ESP32
- **Simple API**: Key-value store seperti database

**Use Case:**
1. User tuning PID via Interface Board
2. Interface send parameter ke Plant Board
3. Plant Board auto-save ke NVS
4. Next power-on: Load parameter terakhir

### 5. Kalman Filter Implementation (AC Motor)

**Algorithm:**
```cpp
// Prediction step
predicted_estimate = estimate;
predicted_error = error_estimate + process_noise;

// Update step
kalman_gain = predicted_error / (predicted_error + error_measure);
estimate = predicted_estimate + kalman_gain * (measurement - predicted_estimate);
error_estimate = (1.0 - kalman_gain) * predicted_error;
```

**Tuning Guide:**
- **process_noise** (Q): Ketidakpastian model (default 0.01)
  - Kecil → filter percaya model, smooth tapi slow
  - Besar → filter percaya measurement, fast tapi noisy
  
- **error_measure** (R): Noise sensor (default 3.0)
  - Kecil → filter percaya sensor sangat akurat
  - Besar → filter assume sensor noisy, lebih smooth

**Performance:**
- Execution time: <0.5ms per sample
- Memory: ~20 bytes (5 float variables)
- Noise reduction: ~70-80% vs raw ADC

### 6. Anti-Windup & Anti-Stall Mechanisms

**Anti-Windup (Integral Clamping):**
```cpp
// Problem: Integral term membesar terus saat error persist
// Solution: Clamp integral sum dalam range aman

integralSum += error * dt;
if (integralSum > INTEGRAL_MAX) integralSum = INTEGRAL_MAX;
if (integralSum < INTEGRAL_MIN) integralSum = INTEGRAL_MIN;

// Effect: Prevent integral windup, faster recovery dari saturation
```

**Anti-Stall (Minimum PWM):**
```cpp
// Problem: Motor stuck karena PWM terlalu kecil (below starting torque)
// Solution: Set minimum PWM threshold

if (output > 0.0 && output < PWM_MIN) 
    output = PWM_MIN;

// Effect: Motor selalu dapat cukup torque untuk bergerak
```

## Performance Metrics

### Timing Analysis

**Interface Board:**
- Main loop: ~10ms cycle time
- Menu render: <5ms (incremental)
- Full redraw: ~50ms (only on menu change)
- Button detection: <1ms
- ESP-NOW TX: ~2ms

**Plant Board:**
- DC PID loop: 50ms (20 Hz)
- AC PID loop: 10ms (100 Hz)
- Encoder ISR: <10µs
- ESP-NOW RX callback: <1ms
- NVS write: ~5ms (non-blocking)

### Memory Usage

**Interface Board (ESP8266/ESP32):**
- Program: ~150KB
- RAM: ~15KB
  - Display buffer: 4KB
  - Speed history: 400 bytes × 2 = 800 bytes
  - PID monitoring: 4KB
  - Stack: ~8KB

**Plant Board (ESP32):**
- Program: ~200KB
- RAM: ~20KB
  - Encoder variables: <1KB
  - PID state: <1KB
  - NVS cache: ~2KB
  - Stack: ~15KB

### Communication Bandwidth

**ESP-NOW (2.4GHz):**
- Max throughput: ~250 kbps (teoritis)
- Actual usage: ~1-2 kbps (8 bytes @ 100 Hz)
- Utilization: <1% (very efficient)
- Range: ~50-100m (line of sight)

## Data Logging & Analysis

### Serial Output Format

**Plant Board (DC Motor):**
```
waktu(ms), encoder_count, rpm, setpoint, error, pwm, kP, kI, kD
1000, 2800, 45.5, 50.0, 4.5, 2048, 1.5, 0.1, 0.05
```

**Plant Board (AC Motor):**
```
waktu(ms), rpm, setpoint, error, dac, kP, kI, kD
1000, 1250.3, 1200.0, -50.3, 180, 2.0, 0.08, 0.04
```

### Data Collection untuk PID Tuning

```bash
# Redirect serial output ke CSV file
platformio device monitor -b 115200 > data_pengukuran.csv

# Buka di Excel/Spreadsheet untuk plot graph
# Kolom: Time, RPM, Setpoint, Error, Output
# Analisis: Rise time, settling time, overshoot, steady-state error
```

## Best Practices

### 1. Development Workflow

```
1. Test hardware standalone (encoder, motor, LCD)
2. Test communication (ESP-NOW ping-pong)
3. Implement control loop (PID) dengan serial debug
4. Integrate dengan interface board
5. Fine-tune PID parameters
6. Add safety features (brownout, overcurrent, timeout)
```

### 2. Safety Considerations

- **Brownout Protection**: Disable detector untuk stabilitas
- **Watchdog Timer**: (Optional) Auto-reset jika system hang
- **Motor Overcurrent**: Limit max PWM jika motor overheat
- **Encoder Sanity Check**: Reset jika count anomali
- **Communication Timeout**: Stop motor jika ESP-NOW disconnect >1s

### 3. Code Organization

```
Plant_Board/
├── include/           # Header files
│   ├── PlantConfig.h  # Pin & constants (UBAH INI)
│   ├── Plant.h        # Motor control functions
│   ├── PID.h          # PID algorithm
│   └── PlantESPNow.h  # Communication protocol
├── src/              # Implementation
│   ├── main.cpp      # Setup & loop
│   ├── Plant.cpp     # Motor & encoder logic
│   ├── PID.cpp       # PID implementation
│   └── PlantESPNow.cpp  # ESP-NOW handlers
└── platformio.ini    # Build config (platform, board, libs)
```

### 4. Debugging Tips

**Serial Debug Levels:**
```cpp
#define DEBUG_LEVEL 2

#if DEBUG_LEVEL >= 1
  Serial.println("Basic info");
#endif

#if DEBUG_LEVEL >= 2
  Serial.print("Detailed: "); Serial.println(value);
#endif

#if DEBUG_LEVEL >= 3
  Serial.println("Verbose ISR debug");
#endif
```

**Performance Profiling:**
```cpp
unsigned long t_start = micros();
// ... code to profile ...
unsigned long t_end = micros();
Serial.print("Execution time: ");
Serial.print(t_end - t_start);
Serial.println(" us");
```

## Future Enhancements

### Possible Improvements

1. **Adaptive PID**: Auto-tuning berdasarkan system response
2. **Web Dashboard**: HTTP server untuk monitoring via browser
3. **Data Logger**: SD card untuk long-term data recording
4. **Multi-Motor**: Kontrol lebih dari 2 motor dengan priority scheduling
5. **Safety Interlocks**: Sensor posisi, limit switch, emergency stop
6. **MQTT Integration**: IoT cloud monitoring (Thingsboard, Blynk)
7. **OTA Update**: Wireless firmware update untuk field deployment
8. **LCD Touch**: Ganti rotary encoder dengan touchscreen
9. **Voice Control**: Integrasi dengan Google Assistant / Alexa
10. **Machine Learning**: Predictive maintenance based on vibration/current

## FAQ (Frequently Asked Questions)

**Q: Kenapa menggunakan ESP-NOW instead of WiFi/MQTT?**
A: ESP-NOW lebih cepat (latency <5ms vs ~50-100ms), tidak perlu router, dan lebih reliable untuk real-time control.

**Q: Bisa ganti ESP8266 dengan ESP32 atau sebaliknya?**
A: Bisa, tapi perlu adjust pin configuration dan library (ESP-NOW API sedikit beda).

**Q: Berapa jarak maksimal ESP-NOW?**
A: ~50-100m line of sight, ~10-30m indoor (tergantung obstacle).

**Q: Kalau MAC address berubah setelah flash?**
A: Kemungkinan ganti board atau flash erase. Cek ulang MAC dan update di config.

**Q: PID sudah optimal, tapi masih oscillate. Kenapa?**
A: Kemungkinan mechanical issue (bearing, load, friction), bukan tuning problem.

**Q: Bisa kontrol motor stepper?**
A: Bisa, tapi perlu ganti library kontrol motor (AccelStepper) dan logika encoder.

**Q: Encoder count selalu reset ke 0. Kenapa?**
A: Kemungkinan ISR overhead atau variable corruption. Gunakan `volatile` dan `portENTER_CRITICAL`.

**Q: LCD kadang glitch saat motor start. Solusi?**
A: Power supply issue. Gunakan capacitor besar (1000µF) di VCC atau power terpisah.

## Development Timeline

- **Fase 1**: Hardware setup & standalone testing (encoder, motor, LCD)
- **Fase 2**: ESP-NOW communication development & testing
- **Fase 3**: PID controller implementation dengan tuning
- **Fase 4**: Interface Board menu system dengan real-time graph
- **Fase 5**: Integration testing & bug fixing
- **Fase 6**: NVS storage & parameter persistence
- **Fase 7**: Kalman filter untuk AC motor
- **Fase 8**: Final optimization & documentation

## References & Resources

### Documentation
- [ESP32 Official Docs](https://docs.espressif.com/projects/esp-idf/en/latest/esp32/)
- [ESP-NOW Guide](https://randomnerdtutorials.com/esp-now-esp32-arduino-ide/)
- [PID Control Theory](https://en.wikipedia.org/wiki/PID_controller)
- [Kalman Filter Explained](https://www.kalmanfilter.net/default.aspx)

### Libraries
- [Adafruit GFX Library](https://github.com/adafruit/Adafruit-GFX-Library)
- [Adafruit ST7735 Library](https://github.com/adafruit/Adafruit-ST7735-Library)
- [ESP32 Preferences](https://github.com/espressif/arduino-esp32/tree/master/libraries/Preferences)

### Tools
- [PlatformIO](https://platformio.org/) - Build system & IDE
- [Serial Plot](https://hackaday.io/project/5334-serialplot-realtime-plotting-software) - Real-time data visualization
- [Logic Analyzer](https://www.saleae.com/) - Debug encoder signals

## Kontributor

Proyek CBL Semester 3 - ITS 2024/2025

**Team Members:**
- [Nama] - Plant Board Development
- [Nama] - Interface Board Development
- [Nama] - PID Tuning & Testing
- [Nama] - Hardware Design & Integration

## Lisensi

Educational Project Pjbl3-8 - Institut Teknologi Sepuluh Nopember (ITS) 2024

---

**Last Updated**: December 5, 2025
**Version**: 1.0
**Dokumentasi**: README.md

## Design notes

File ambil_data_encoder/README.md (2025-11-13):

# Ambil Data Encoder

Program untuk mengambil dan membaca data dari encoder motor DC menggunakan ESP32.

## Deskripsi

Program ini membaca pulsa encoder motor DC dengan resolusi quadrature (4x) dan menghitung kecepatan motor dalam RPM. Data ditampilkan melalui Serial Monitor.

## Fitur

- Pembacaan encoder quadrature (Pin A & B)
- Perhitungan RPM real-time
- Interrupt-based encoder reading
- Timer-based sampling (10ms interval)
- Kontrol PWM motor DC

## Pin Configuration

| Komponen | Pin |
|---|-----|
| Encoder A | GPIO 34 |
| Encoder B | GPIO 35 |
| Motor PWM | GPIO 13 |
| Motor DIR | GPIO 22 |
| LED WiFi | GPIO 21 |

## Output Serial

Format: `encoder_count, pulse_count, rpm`

Contoh:
```
1024 , 14 , 120.5
1038 , 14 , 120.5
```

## Build & Upload

```bash
platformio run --target upload
platformio device monitor
```

## Parameter

- **PPR**: 14 (Pulses Per Revolution)
- **Sampling Rate**: 10ms
- **Baud Rate**: 115200

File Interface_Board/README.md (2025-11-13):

# Interface Board

Board kontrol interface untuk sistem escalator menggunakan ESP32/ESP8266 dengan LCD dan rotary encoder.

## Deskripsi

Interface board berfungsi sebagai control panel untuk mengatur dan memonitor sistem escalator. Menggunakan LCD ST7735 untuk display, rotary encoder untuk input, dan ESP-NOW untuk komunikasi wireless dengan Plant Board.

## Fitur

- **LCD Display**: ST7735 TFT Display untuk menampilkan menu dan status
- **Rotary Encoder**: Input kontrol dengan push button
- **ESP-NOW**: Komunikasi wireless dengan Plant Board
- **WiFi AP Mode**: Access point untuk koneksi jaringan
- **Menu System**: Sistem menu navigasi lengkap
- **Real-time Monitoring**: Monitor kecepatan dan status escalator

## Pin Configuration

### ESP32
| Komponen | Pin |
|---|-----|
| TFT CS | GPIO 15 |
| TFT RST | GPIO 4 |
| TFT DC | GPIO 5 |
| Encoder CLK | GPIO 27 |
| Encoder DT | GPIO 26 |
| Encoder SW | GPIO 25 |
| LED Status | GPIO 13 |

### ESP8266
| Komponen | Pin |
|---|-----|
| TFT CS | GPIO 15 |
| TFT RST | GPIO 4 |
| TFT DC | GPIO 5 |
| Encoder CLK | GPIO 12 |
| Encoder DT | GPIO 2 |
| Encoder SW | GPIO 16 |

## Struktur Menu

1. Status Monitor
2. Escalator Control
3. Motor AC Control
4. PID Settings
5. Network Status

## Build & Upload

```bash
# Build project
platformio run

# Upload ke ESP32/ESP8266
platformio run --target upload

# Monitor serial
platformio device monitor
```

## Konfigurasi

Edit `include/PinConfig.h` untuk:
- WiFi AP SSID & Password
- Plant Board MAC Address
- Pin configuration

## Testing

Tersedia test program encoder di `test/encoder_test.cpp` untuk debugging rotary encoder.

## Dependencies

- Adafruit GFX Library
- Adafruit ST7735 Library
- ESP-NOW (built-in)

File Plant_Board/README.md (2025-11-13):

# Plant Board

Board kontrol utama untuk sistem escalator dengan kontrol motor DC, motor AC, PID controller, dan komunikasi ESP-NOW.

## Deskripsi

Plant Board adalah controller utama yang mengendalikan motor DC dan AC pada escalator. Board ini menerima command dari Interface Board melalui ESP-NOW dan mengirimkan data sensor kembali untuk monitoring.

## Fitur

- **DC Motor Control**: Kontrol kecepatan motor DC dengan PWM
- **AC Motor Control**: Kontrol motor AC dengan DAC
- **Encoder Reading**: Pembacaan encoder untuk feedback kecepatan
- **PID Controller**: Kontrol kecepatan motor dengan PID
- **ESP-NOW Communication**: Komunikasi wireless dengan Interface Board
- **LED Indicators**: Indikator status untuk berbagai fungsi
- **Sensor Support**: Support untuk sensor suhu dan arus

## Pin Configuration

### Motor DC
| Komponen | Pin |
|---|-----|
| Motor PWM | GPIO 13 |
| Motor DIR | GPIO 22 |
| Encoder A | GPIO 34 |
| Encoder B | GPIO 35 |

### Motor AC
| Komponen | Pin |
|---|-----|
| DAC 1 | GPIO 25 |
| DAC 2 | GPIO 26 |
| DAC Source | GPIO 27 |
| Voltage Select | GPIO 12 |
| AC Encoder | GPIO 32 |

### LED Indicators
| LED | Pin | Fungsi |
|-----|-----|---|
| WiFi | GPIO 21 | Status WiFi |
| PID | GPIO 19 | PID Active |
| DC Control | GPIO 18 | DC Motor Control |
| AC Control | GPIO 5 | AC Motor Control |

### Sensors
| Sensor | Pin |
|---|-----|
| Speed Sensor | GPIO 36 |
| Temp Sensor | GPIO 39 |
| Current Sensor | GPIO 33 |

## Parameter Motor

- **PPR (Pulses Per Revolution)**: 14
- **DC Read Interval**: 5ms
- **AC Read Interval**: 5ms
- **PWM Frequency**: 5000 Hz
- **PWM Resolution**: 8-bit (0-255)

## PID Settings

- Default PID Interval: 5ms
- Tunable parameters: Kp, Ki, Kd

## Network Configuration

- **Interface MAC**: `{0x50, 0x02, 0x91, 0x78, 0x72, 0xA7}`
- **Data Send Interval**: 1000ms (1 detik)

## Build & Upload

```bash
# Build project
platformio run

# Upload ke ESP32
platformio run --target upload

# Monitor serial
platformio device monitor
```

## Konfigurasi

Edit `include/PlantConfig.h` untuk:
- Pin assignments
- Motor parameters
- PID settings
- Network configuration
- Interface Board MAC Address

## Class Structure

- **Plant**: Main control class
- **PlantESPNow**: ESP-NOW communication handler
- **PID**: PID controller
- **LedControl**: LED indicator management

## Dependencies

- ESP-NOW (built-in)
- Arduino Framework

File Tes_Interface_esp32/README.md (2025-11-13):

# Tes Interface ESP32

Project testing untuk Interface Board menggunakan ESP32 dengan fokus pada debugging dan validasi komponen.

## Deskripsi

Project ini berisi kode testing dan contoh implementasi untuk Interface Board. Berguna untuk debugging komponen seperti encoder, LCD, dan network sebelum implementasi final.

## Fitur Testing

- **Encoder Debug**: Logging detail untuk rotary encoder
- **LCD Test**: Test display ST7735
- **Network Test**: Test ESP-NOW dan WiFi AP
- **Menu System Demo**: Contoh implementasi menu system
- **Pin State Monitoring**: Real-time monitoring status pin

## File Penting

- `main.cpp`: Program encoder debug dan logging
- `main_example.cpp.txt`: Contoh implementasi lengkap menu system
- `network_example.cpp.txt`: Contoh implementasi network
- `ControlMenuSystem.cpp`: Implementasi sistem menu
- `EncoderControl.cpp`: Handler rotary encoder
- `NetworkManager.cpp`: Manager komunikasi network

## Program Encoder Debug

Program utama (`main.cpp`) untuk testing encoder dengan fitur:
- Interrupt-based encoder reading
- Real-time position tracking
- Trigger counting
- Debouncing
- Button reset

### Output Debug

```
ENCODER DEBUG & LOGGING TEST
========================================
CLK Pin: 27
DT Pin: 26
SW Pin: 25
========================================
encoder0Pin States: CLK=1, DT=1, SW=1
encoder1Pin States: CLK=0, DT=1, SW=1
```

## Pin Configuration

Sama dengan Interface Board (lihat `include/PinConfig.h`):

| Komponen | Pin ESP32 |
|---|---|
| Encoder CLK | GPIO 27 |
| Encoder DT | GPIO 26 |
| Encoder SW | GPIO 25 |
| TFT CS | GPIO 15 |
| TFT RST | GPIO 4 |
| TFT DC | GPIO 5 |

## Cara Menggunakan

### 1. Test Encoder
```bash
# Upload program default (encoder debug)
platformio run --target upload
platformio device monitor
```

Putar encoder dan lihat output di serial monitor.

### 2. Test Full Menu System

Rename file untuk testing:
```bash
# Backup main.cpp
mv src/main.cpp src/main_debug.cpp

# Gunakan example
cp src/main_example.cpp.txt src/main.cpp

# Upload
platformio run --target upload
```

### 3. Test Network Only

```bash
cp src/network_example.cpp.txt src/main.cpp
platformio run --target upload
```

## Build & Upload

```bash
# Build
platformio run

# Upload
platformio run --target upload

# Monitor
platformio device monitor -b 115200
```

## Debugging Tips

1. **Encoder tidak terbaca**: Cek koneksi pullup dan debouncing
2. **LCD blank**: Cek pin RST dan power supply
3. **ESP-NOW gagal**: Cek MAC address di PinConfig.h
4. **Serial tidak muncul**: Pastikan baud rate 115200

## Dependencies

- Adafruit GFX Library
- Adafruit ST7735 Library
- WiFi (built-in)
- ESP-NOW (built-in)

## Notes

Project ini adalah versi development/testing. Untuk implementasi final, gunakan project `Interface_Board`.

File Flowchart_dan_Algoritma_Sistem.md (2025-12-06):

# Flowchart dan Logika Algoritma Sistem Plant Board & Interface Board

## 1. SISTEM PLANT BOARD

### 1.1 Flowchart Utama Plant Board

```
┌─────────────────────┐
│   START (Setup)     │
└──────────┬──────────┘
           │
           ▼
┌─────────────────────────┐
│ Disable Brownout        │
└──────────┬──────────────┘
           │
           ▼
┌─────────────────────────┐
│ Init LED Control        │
└──────────┬──────────────┘
           │
           ▼
┌─────────────────────────┐
│ Init ESP-NOW            │
└──────────┬──────────────┘
           │
           ▼
┌─────────────────────────┐
│ Init Data Storage       │
│ (Load PID Parameters)   │
└──────────┬──────────────┘
           │
           ▼
┌─────────────────────────┐
│ Init DC Motor           │
│ - Encoder               │
│ - Timer                 │
└──────────┬──────────────┘
           │
           ▼
┌─────────────────────────┐
│ Init AC Motor           │
│ - Encoder               │
│ - Timer                 │
│ - Kalman Filter         │
└──────────┬──────────────┘
           │
           ▼
┌─────────────────────────┐
│ Update PID Parameters   │
│ to Interface Board      │
└──────────┬──────────────┘
           │
           ▼
┌─────────────────────────┐
│    MAIN LOOP            │
└──────────┬──────────────┘
           │
           ▼
       ┌───┴───┐
       │       │
       ▼       ▼
   ┌─────┐ ┌─────┐
   │ DC  │ │ AC  │
   │Speed│ │Speed│
   │Req? │ │Req? │
   └──┬──┘ └──┬──┘
      │       │
      ▼       ▼
   ┌─────┐ ┌─────┐
   │DC   │ │AC   │
   │PID  │ │PID  │
   │Proc.│ │Proc.│
   └──┬──┘ └──┬──┘
      │       │
      └───┬───┘
          │
          ▼
      (Loop Back)
```

### 1.2 Algoritma DC Motor Control dengan PID

```
ALGORITMA: DC_Motor_PID_Control
INPUT: DCsetpoint (target RPM), DCMode (ON/OFF), PIDMODE (PID/Manual)
OUTPUT: PWM signal ke motor DC

MULAI
1. Timer Interrupt setiap DCREAD_INTERVAL (50ms)
   - Set flag DCnewDataReady = TRUE
   - Jika dcspeedRequest = FALSE, matikan motor

2. JIKA DCnewDataReady = TRUE
   a. Baca encoder:
      - DCpulseCount = DCencoder - DClastEncoder
      - DClastEncoder = DCencoder
   
   b. Hitung RPM:
      - DCrpm = (abs(DCpulseCount) * 60000) / (DCREAD_INTERVAL * PPR)
      - DCGearboxRPM = DCrpm / 200  // Gear ratio 200:1
   
   c. PILIH mode kontrol:
      
      JIKA (DCMode = TRUE) DAN (PIDMODE = TRUE):
         ├─ Hitung Error:
         │  Error = DCsetpoint - DCGearboxRPM
         │
         ├─ Hitung Proportional:
         │  P = DCkP × Error
         │
         ├─ Hitung Integral (dengan anti-windup):
         │  DCintegralSum += Error × dt
         │  JIKA DCintegralSum > DC_INTEGRAL_MAX:
         │     DCintegralSum = DC_INTEGRAL_MAX
         │  JIKA DCintegralSum < DC_INTEGRAL_MIN:
         │     DCintegralSum = DC_INTEGRAL_MIN
         │  I = DCkI × DCintegralSum
         │
         ├─ Hitung Derivative:
         │  D = DCkD × (Error - DCpreviousError) / dt
         │  DCpreviousError = Error
         │
         ├─ Total Output:
         │  DCsignalPWM = (P + I + D) × 10
         │
         ├─ Saturasi Output (dengan anti-stall):
         │  JIKA DCsignalPWM > 4095:
         │     DCsignalPWM = 4095
         │  JIKA DCsignalPWM < -4095:
         │     DCsignalPWM = -4095
         │  JIKA 0 < DCsignalPWM < DC_PWM_MIN (800):
         │     DCsignalPWM = DC_PWM_MIN  // Anti-stall
         │  JIKA -DC_PWM_MIN < DCsignalPWM < 0:
         │     DCsignalPWM = -DC_PWM_MIN
         │
         └─ Kirim PWM ke motor:
            DCmotorControl(DCDirection, DCsignalPWM)
      
      JIKA (DCMode = TRUE) DAN (PIDMODE = FALSE):
         ├─ Manual control (tanpa PID):
         │  PWM = map(DCsetpoint, 0, 115, 0, 4095)
         └─ DCmotorControl(DCDirection, PWM)
      
      JIKA (DCMode = FALSE):
         └─ Matikan motor:
            DCmotorControl(0, 0)
   
   d. Kirim data via ESP-NOW:
      - Kirim DCGearboxRPM ke Interface Board
      - Kirim timestamp

3. DCnewDataReady = FALSE

SELESAI
```

### 1.3 Algoritma AC Motor Control dengan PID

```
ALGORITMA: AC_Motor_PID_Control
INPUT: ACsetpoint (target RPM), ACMode (ON/OFF), PIDMODE (PID/Manual)
OUTPUT: PWM signal ke motor AC

MULAI
1. Timer Interrupt setiap ACREAD_INTERVAL
   - Set flag ACnewDataReady = TRUE
   - Jika acspeedRequest = FALSE, matikan motor

2. JIKA ACnewDataReady = TRUE
   a. Baca encoder dengan Kalman Filter:
      - Raw measurement dari encoder
      - Kalman Filter untuk smoothing:
        * Predict: estimate = previous estimate
        * error_estimate = previous error_estimate + process_noise
        * Update: kalman_gain = error_estimate / (error_estimate + error_measure)
        * estimate = estimate + kalman_gain × (measurement - estimate)
        * error_estimate = (1 - kalman_gain) × error_estimate
      - ACrpm = filtered estimate
   
   b. PILIH mode kontrol:
      
      JIKA (ACMode = TRUE) DAN (PIDMODE = TRUE):
         ├─ Hitung Error:
         │  ACError = ACsetpoint - ACrpm
         │
         ├─ Hitung Proportional:
         │  P = ACkP × ACError
         │
         ├─ Hitung Integral (dengan anti-windup):
         │  ACintegralSum += ACError × dt
         │  JIKA ACintegralSum > AC_INTEGRAL_MAX:
         │     ACintegralSum = AC_INTEGRAL_MAX
         │  JIKA ACintegralSum < AC_INTEGRAL_MIN:
         │     ACintegralSum = AC_INTEGRAL_MIN
         │  I = ACkI × ACintegralSum
         │
         ├─ Hitung Derivative:
         │  D = ACkD × (ACError - ACpreviousError) / dt
         │  ACpreviousError = ACError
         │
         ├─ Total Output:
         │  ACsignalPWM = P + I + D
         │
         ├─ Saturasi Output (dengan anti-stall):
         │  JIKA ACsignalPWM > 255:
         │     ACsignalPWM = 255
         │  JIKA ACsignalPWM < 0:
         │     ACsignalPWM = 0
         │  JIKA 0 < ACsignalPWM < AC_PWM_MIN (800):
         │     ACsignalPWM = AC_PWM_MIN  // Anti-stall
         │
         └─ Kirim PWM ke motor:
            ACmotorControl(true, ACsignalPWM, true, 0)
      
      JIKA (ACMode = TRUE) DAN (PIDMODE = FALSE):
         ├─ Manual control (tanpa PID):
         │  PWM = map(ACsetpoint, 0, 1500, 0, 255)
         └─ ACmotorControl(true, PWM, true, 0)
      
      JIKA (ACMode = FALSE):
         └─ Matikan motor dan reset PID:
            ACmotorControl(false, 0, true, 0)
            ACintegralSum = 0
            ACpreviousError = 0

3. ACnewDataReady = FALSE

SELESAI
```

### 1.4 Algoritma Komunikasi ESP-NOW (Plant Board)

```
ALGORITMA: ESP-NOW_Communication_Plant
FUNGSI: Terima perintah dari Interface Board

MULAI

1. INIT ESP-NOW:
   - Set WiFi mode = WIFI_STA
   - Init ESP-NOW
   - Register callback: OnDataSent, OnDataReceived
   - Add peer (Interface Board MAC address)

2. CALLBACK OnDataReceived(mac, data, len):
   - Parse message: typeId (4 bytes) + value (4 bytes)
   
   PILIH berdasarkan typeId:
   
   CASE MSG_DC_KP (11):
      ├─ DCkP = value
      └─ Simpan ke EEPROM
   
   CASE MSG_DC_KI (12):
      ├─ DCkI = value
      └─ Simpan ke EEPROM
   
   CASE MSG_DC_KD (13):
      ├─ DCkD = value
      └─ Simpan ke EEPROM
   
   CASE MSG_DC_Setpoint (14):
      └─ DCsetpoint = value
   
   CASE MSG_DC_Control (15):
      └─ DCMode = value (ON/OFF)
   
   CASE MSG_DC_Direction (16):
      └─ DCDirection = value (0/1)
   
   CASE MSG_AC_KP (21):
      ├─ ACkP = value
      └─ Simpan ke EEPROM
   
   CASE MSG_AC_KI (22):
      ├─ ACkI = value
      └─ Simpan ke EEPROM
   
   CASE MSG_AC_KD (23):
      ├─ ACkD = value
      └─ Simpan ke EEPROM
   
   CASE MSG_AC_Setpoint (24):
      └─ ACsetpoint = value
   
   CASE MSG_AC_Control (25):
      └─ ACMode = value (ON/OFF)
   
   CASE MSG_PID_MODE (30):
      └─ PIDMODE = value (PID/Manual)
   
   CASE MSG_SPD_REQUEST (31):
      ├─ Parse value:
      │  dcspeedRequest = (value == 1 atau value == 3)
      │  acspeedRequest = (value == 2 atau value == 3)
      └─ JIKA value == 1 atau 3:
            waktu_awal_motor = millis()
   
   CASE ESP_RESTART (100):
      └─ ESP.restart()

3. CALLBACK OnDataSent(mac, status):
   - Log status pengiriman (success/fail)

4. FUNGSI sendTaggedFloat(typeId, value):
   - Buat paket: [typeId(4B), value(4B)]
   - Kirim via esp_now_send()

SELESAI
```

---

## 2. SISTEM INTERFACE BOARD

### 2.1 Flowchart Utama Interface Board

```
┌─────────────────────┐
│   START (Setup)     │
└──────────┬──────────┘
           │
           ▼
┌─────────────────────────┐
│ Init Serial (115200)    │
└──────────┬──────────────┘
           │
           ▼
┌─────────────────────────┐
│ Init ESP-NOW            │
└──────────┬──────────────┘
           │
           ▼
┌─────────────────────────┐
│ Init Rotary Encoder     │
└──────────┬──────────────┘
           │
           ▼
┌─────────────────────────┐
│ Init TFT Display        │
│ (ST7735)                │
└──────────┬──────────────┘
           │
           ▼
┌─────────────────────────┐
│ Menu System Init        │
│ (Show Splash Screen)    │
└──────────┬──────────────┘
           │
           ▼
┌─────────────────────────┐
│ Send ESP_RESTART        │
│ to Plant Board          │
└──────────┬──────────────┘
           │
           ▼
┌─────────────────────────┐
│    MAIN LOOP            │
└──────────┬──────────────┘
           │
           ▼
┌─────────────────────────┐
│ Baca Rotary Encoder     │
│ (Cek perubahan posisi)  │
└──────────┬──────────────┘
           │
           ▼
      ┌────┴────┐
      │ Posisi  │ NO
      │Berubah? ├──────┐
      └────┬────┘      │
          YES          │
           │           │
           ▼           │
┌─────────────────────┐│
│ menuNavigate()      ││
│ (Scroll menu)       ││
└─────────┬───────────┘│
          │            │
          └────────────┤
                       │
           ┌───────────┘
           │
           ▼
┌─────────────────────────┐
│ Baca Button Click       │
└──────────┬──────────────┘
           │
      ┌────┴────────────┐
      │                 │
      ▼                 ▼
┌──────────┐      ┌──────────┐
│ Single   │      │ Double   │
│ Click?   │      │ Click?   │
└────┬─────┘      └────┬─────┘
     │YES              │YES
     ▼                 ▼
┌──────────┐      ┌──────────────┐
│menuSelect│      │menuDoubleClick│
│(Enter)   │      │(Toggle Run/  │
└────┬─────┘      │Encoder Mode) │
     │            └────┬─────────┘
     │                 │
     └────────┬────────┘
              │
              ▼
         ┌─────────┐
         │  Long   │
         │ Click?  │
         └────┬────┘
             YES
              │
              ▼
         ┌─────────┐
         │menuBack │
         │(Kembali)│
         └────┬────┘
              │
              └────────┐
                       │
           ┌───────────┘
           │
           ▼
┌─────────────────────────┐
│ menuUpdate()            │
│ (Update display)        │
└──────────┬──────────────┘
           │
           ▼
       (Loop Back)
```

### 2.2 Algoritma Menu Navigation System

```
ALGORITMA: Menu_Navigation_System
TUJUAN: Navigasi dan kontrol menu pada TFT display

MULAI

STRUKTUR MENU:
Menu Level 0 (Root):
├─ [0] Escalator (DC Motor)
├─ [1] Motor AC
└─ [2] WiFi Status

Menu Level 1 (Escalator):
├─ [0] Graph View (Real-time monitoring)
└─ [1] Control View (Parameter setting)

Menu Level 1 (Motor AC):
├─ [0] Graph View (Real-time monitoring)
└─ [1] Control View (Parameter setting)

1. FUNGSI menuNavigate(direction):
   ├─ JIKA g_currentMenu == 0 (Root Menu):
   │  ├─ Update g_selectedIndex (0-2)
   │  └─ Gambar ulang menu
   │
   ├─ JIKA g_currentMenu == 1 (Escalator):
   │  ├─ JIKA g_escSubMenu == 0 (Graph):
   │  │  └─ (Tidak ada navigasi di graph)
   │  │
   │  └─ JIKA g_escSubMenu == 1 (Control):
   │     ├─ Update g_selectedIndex (0-5):
   │     │  [0] Kp, [1] Ki, [2] Kd
   │     │  [3] Setpoint, [4] Run/Stop, [5] Direction
   │     └─ Gambar ulang menu
   │
   └─ JIKA g_currentMenu == 2 (Motor AC):
      ├─ JIKA g_motorSubMenu == 0 (Graph):
      │  └─ (Tidak ada navigasi di graph)
      │
      └─ JIKA g_motorSubMenu == 1 (Control):
         ├─ Update g_selectedIndex (0-4):
         │  [0] Kp, [1] Ki, [2] Kd
         │  [3] Setpoint, [4] Run/Stop
         └─ Gambar ulang menu

2. FUNGSI menuSelect():
   ├─ JIKA g_currentMenu == 0 (Root Menu):
   │  ├─ JIKA g_selectedIndex == 0:
   │  │  ├─ g_currentMenu = 1 (Escalator)
   │  │  ├─ g_escSubMenu = 0 (Graph)
   │  │  └─ Minta speed request ke Plant Board
   │  │
   │  ├─ JIKA g_selectedIndex == 1:
   │  │  ├─ g_currentMenu = 2 (Motor AC)
   │  │  ├─ g_motorSubMenu = 0 (Graph)
   │  │  └─ Minta speed request ke Plant Board
   │  │
   │  └─ JIKA g_selectedIndex == 2:
   │     ├─ g_currentMenu = 3 (WiFi Status)
   │     └─ Tampilkan status koneksi
   │
   ├─ JIKA g_currentMenu == 1 (Escalator):
   │  ├─ JIKA g_escSubMenu == 0 (Graph):
   │  │  └─ g_escSubMenu = 1 (Switch ke Control)
   │  │
   │  └─ JIKA g_escSubMenu == 1 (Control):
   │     ├─ JIKA g_isEditing == FALSE:
   │     │  └─ g_isEditing = TRUE (Mulai edit parameter)
   │     │
   │     └─ JIKA g_isEditing == TRUE:
   │        ├─ Simpan nilai parameter
   │        ├─ Kirim via ESP-NOW ke Plant Board:
   │        │  • sendTaggedFloat(MSG_DC_KP, g_dcKp)
   │        │  • sendTaggedFloat(MSG_DC_KI, g_dcKi)
   │        │  • sendTaggedFloat(MSG_DC_KD, g_dcKd)
   │        │  • sendTaggedFloat(MSG_DC_Setpoint, g_dcSetpoint)
   │        │  • sendTaggedFloat(MSG_DC_Control, g_escRunning)
   │        │  • sendTaggedFloat(MSG_DC_Direction, g_escDirection)
   │        └─ g_isEditing = FALSE
   │
   └─ JIKA g_currentMenu == 2 (Motor AC):
      ├─ JIKA g_motorSubMenu == 0 (Graph):
      │  └─ g_motorSubMenu = 1 (Switch ke Control)
      │
      └─ JIKA g_motorSubMenu == 1 (Control):
         ├─ JIKA g_isEditing == FALSE:
         │  └─ g_isEditing = TRUE (Mulai edit parameter)
         │
         └─ JIKA g_isEditing == TRUE:
            ├─ Simpan nilai parameter
            ├─ Kirim via ESP-NOW ke Plant Board:
            │  • sendTaggedFloat(MSG_AC_KP, g_acKp)
            │  • sendTaggedFloat(MSG_AC_KI, g_acKi)
            │  • sendTaggedFloat(MSG_AC_KD, g_acKd)
            │  • sendTaggedFloat(MSG_AC_Setpoint, g_acSetpoint)
            │  • sendTaggedFloat(MSG_AC_Control, g_motorRunning)
            └─ g_isEditing = FALSE

3. FUNGSI menuBack():
   ├─ JIKA g_isEditing == TRUE:
   │  └─ g_isEditing = FALSE (Cancel edit)
   │
   ├─ JIKA g_escSubMenu == 1 ATAU g_motorSubMenu == 1:
   │  ├─ Reset ke submenu 0 (Graph)
   │  └─ Stop speed request
   │
   └─ JIKA g_currentMenu > 0:
      ├─ g_currentMenu = 0 (Kembali ke Root)
      └─ g_selectedIndex = 0

4. FUNGSI menuDoubleClick():
   ├─ JIKA di Graph View:
   │  └─ Toggle motor Run/Stop:
   │     ├─ g_escRunning = !g_escRunning
   │     └─ Kirim MSG_DC_Control atau MSG_AC_Control
   │
   └─ JIKA di mode lain:
      └─ Toggle encoder direction (UP/DOWN)

5. FUNGSI menuUpdate():
   ├─ Cek flag g_escSpeedUpdated:
   │  └─ JIKA TRUE:
   │     ├─ Update graph dengan data baru
   │     ├─ Redraw incremental (oscilloscope style)
   │     └─ g_escSpeedUpdated = FALSE
   │
   ├─ Cek flag g_motorSpeedUpdated:
   │  └─ JIKA TRUE:
   │     ├─ Update graph dengan data baru
   │     ├─ Redraw incremental (oscilloscope style)
   │     └─ g_motorSpeedUpdated = FALSE
   │
   └─ Update status indicators (connection, run state)

SELESAI
```

### 2.3 Algoritma Real-time Graph Display

```
ALGORITMA: Real_Time_Graph_Display
TUJUAN: Menampilkan grafik real-time dengan gaya oscilloscope

MULAI

KONSTANTA:
- innerWidth = 116 pixels
- maxSamples = 100 data points
- ESC_GRAPH_MAX = 115.0 (DC Motor)
- AC_GRAPH_MAX = 1500.0 (AC Motor)

1. FUNGSI drawEscGraph(fullRedraw):
   ├─ JIKA fullRedraw ATAU !escGraphInit:
   │  ├─ Clear graph area
   │  ├─ Draw border (5, 25, 118, 70)
   │  ├─ Draw setpoint line (red, dashed):
   │  │  setpointY = 94 - (g_dcSetpoint × 69 / ESC_GRAPH_MAX)
   │  │  Draw horizontal line at setpointY
   │  │
   │  ├─ Draw time grid (vertical lines per 1 second)
   │  │
   │  ├─ Plot all historical data:
   │  │  UNTUK col = 0 sampai innerWidth:
   │  │     ├─ Interpolate data index dari history buffer
   │  │     ├─ idx = (g_escHistoryIndex - 1 - offset) % maxSamples
   │  │     ├─ value = g_escSpeedHistory[idx]
   │  │     ├─ y = 94 - (value × 69 / ESC_GRAPH_MAX)
   │  │     ├─ Clamp y ke range [25, 94]
   │  │     ├─ Draw pixel(col + leftX, y, YELLOW)
   │  │     └─ escGraphY[col] = y
   │  │
   │  └─ escGraphInit = TRUE
   │
   └─ JIKA incremental update:
      ├─ Shift graph 1 pixel ke kiri:
      │  UNTUK col = 0 sampai innerWidth-2:
      │     ├─ oldY = escGraphY[col]
      │     ├─ newY = escGraphY[col+1]
      │     ├─ Erase pixel(col + leftX, oldY, BLACK)
      │     ├─ Draw pixel(col + leftX, newY, YELLOW)
      │     └─ escGraphY[col] = newY
      │
      └─ Draw newest data di rightmost column:
         ├─ value = g_escSpeedHistory[g_escHistoryIndex-1]
         ├─ y = 94 - (value × 69 / ESC_GRAPH_MAX)
         ├─ Clamp y
         ├─ Draw pixel(rightX, y, YELLOW)
         └─ escGraphY[innerWidth-1] = y

2. FUNGSI updateEscalatorSpeed(speed):
   ├─ Simpan ke circular buffer:
   │  g_escSpeedHistory[g_escHistoryIndex] = speed
   │  g_escHistoryIndex = (g_escHistoryIndex + 1) % maxSamples
   │
   ├─ Update current speed display:
   │  g_escSpeed = speed
   │
   └─ Set flag untuk update graph:
      g_escSpeedUpdated = TRUE

3. FUNGSI drawMotorGraph(fullRedraw):
   ├─ Sama seperti drawEscGraph() tetapi dengan:
   │  ├─ AC_GRAPH_MAX = 1500.0
   │  ├─ Data dari g_motorSpeedHistory[]
   │  └─ Setpoint dari g_acSetpoint
   │
   └─ (Implementasi identik dengan penyesuaian variabel)

4. FUNGSI updateMotorSpeed(speed):
   ├─ Simpan ke circular buffer:
   │  g_motorSpeedHistory[g_motorHistoryIndex] = speed
   │  g_motorHistoryIndex = (g_motorHistoryIndex + 1) % maxSamples
   │
   ├─ Update current speed display:
   │  g_motorSpeed = speed
   │
   └─ Set flag untuk update graph:
      g_motorSpeedUpdated = TRUE

SELESAI
```

### 2.4 Algoritma Encoder Input Processing

```
ALGORITMA: Rotary_Encoder_Input
TUJUAN: Membaca rotary encoder untuk navigasi menu

MULAI

VARIABEL:
- lastEncoder = posisi encoder sebelumnya
- encoderMode = ENCODER_UP atau ENCODER_DOWN
- buttonState = status tombol encoder

1. FUNGSI DCgetEncoderCount():
   ├─ Baca posisi encoder saat ini
   └─ Return: long encoder count

2. FUNGSI getEncoderMode():
   ├─ Return: ENCODER_UP atau ENCODER_DOWN
   └─ (Menentukan arah increment/decrement)

3. FUNGSI toggleEncoderMode():
   ├─ JIKA encoderMode == ENCODER_UP:
   │  └─ encoderMode = ENCODER_DOWN
   │
   └─ JIKA encoderMode == ENCODER_DOWN:
      └─ encoderMode = ENCODER_UP

4. FUNGSI getButtonClick():
   ├─ Baca state tombol encoder
   │
   ├─ Deteksi Single Click:
   │  ├─ Button pressed lalu released dalam < 500ms
   │  └─ Return: CLICK_SINGLE
   │
   ├─ Deteksi Double Click:
   │  ├─ 2x click dalam < 300ms
   │  └─ Return: CLICK_DOUBLE
   │
   ├─ Deteksi Long Press:
   │  ├─ Button held > 1000ms
   │  └─ Return: CLICK_LONG
   │
   └─ JIKA tidak ada event:
      └─ Return: CLICK_NONE

5. MAIN LOOP Processing:
   ├─ currentEncoder = DCgetEncoderCount()
   │
   ├─ JIKA currentEncoder != lastEncoder:
   │  ├─ direction = (currentEncoder > lastEncoder) ? 1 : -1
   │  ├─ JIKA g_isEditing == TRUE:
   │  │  ├─ Update parameter value:
   │  │  │  JIKA encoderMode == ENCODER_UP:
   │  │  │     value += increment × direction
   │  │  │  JIKA encoderMode == ENCODER_DOWN:
   │  │  │     value -= increment × direction
   │  │  └─ Redraw parameter display
   │  │
   │  └─ JIKA g_isEditing == FALSE:
   │     └─ menuNavigate(direction)
   │
   └─ lastEncoder = currentEncoder

SELESAI
```

### 2.5 Algoritma Komunikasi ESP-NOW (Interface Board)

```
ALGORITMA: ESP-NOW_Communication_Interface
FUNGSI: Terima data dari Plant Board dan kirim perintah kontrol

MULAI

1. INIT ESP-NOW:
   - Set WiFi mode = WIFI_STA
   - Init ESP-NOW
   - Register callback: OnDataSent, OnDataReceived
   - Add peer (Plant Board MAC address)

2. CALLBACK receiveData(mac, data, len):
   - Parse message: typeId (4 bytes) + value (4 bytes)
   
   PILIH berdasarkan typeId:
   
   CASE MSG_DC_SPEED (10):
      ├─ DCspeed = value
      ├─ updateEscalatorSpeed(value)
      ├─ Update g_escConnected = TRUE
      └─ Set flag g_escSpeedUpdated = TRUE
   
   CASE MSG_DC_KP (11):
      └─ g_dcKp = value (update tampilan)
   
   CASE MSG_DC_KI (12):
      └─ g_dcKi = value
   
   CASE MSG_DC_KD (13):
      └─ g_dcKd = value
   
   CASE MSG_DC_Setpoint (14):
      └─ g_dcSetpoint = value
   
   CASE MSG_AC_SPEED (20):
      ├─ ACspeed = value
      ├─ updateMotorSpeed(value)
      ├─ Update g_motorConnected = TRUE
      └─ Set flag g_motorSpeedUpdated = TRUE
   
   CASE MSG_AC_KP (21):
      └─ g_acKp = value
   
   CASE MSG_AC_KI (22):
      └─ g_acKi = value
   
   CASE MSG_AC_KD (23):
      └─ g_acKd = value
   
   CASE MSG_AC_Setpoint (24):
      └─ g_acSetpoint = value
   
   CASE MSG_TIMESTAMP (32):
      ├─ timestamp = value
      └─ addTimestamp(timestamp)  // Simpan ke buffer untuk graph
   
   DEFAULT:
      └─ Log unknown message type

3. FUNGSI sendTaggedFloat(typeId, value):
   ├─ Buat paket: [typeId(4B), value(4B)]
   ├─ esp_now_send(PLANT_MAC, paket, 8)
   └─ Log pengiriman

4. FUNGSI onDataSent(mac, status):
   ├─ JIKA status == ESP_NOW_SEND_SUCCESS:
   │  └─ Log sukses
   │
   └─ JIKA status == FAIL:
      ├─ Log error
      └─ Update g_espnowInit = FALSE

5. TIMING & BUFFER MANAGEMENT:
   ├─ addTimestamp(ts):
   │  ├─ timestamp_buffer[timestamp_idx] = ts
   │  ├─ timestamp_idx = (timestamp_idx + 1) % TIMESTAMP_BUF
   │  └─ (Circular buffer untuk 100 timestamp)
   │
   └─ getTimestamp(index):
      ├─ Ambil timestamp dari buffer
      └─ Return: timestamp atau -1 jika tidak ada data

SELESAI
```

---

## 3. DIAGRAM INTERAKSI SISTEM

```
┌─────────────────────────────────────────────────────────────┐
│                    INTERFACE BOARD                          │
│  ┌────────────┐  ┌──────────────┐  ┌──────────────────┐   │
│  │  Rotary    │  │  TFT Display │  │   ESP-NOW TX     │   │
│  │  Encoder   │  │  (ST7735)    │  │   (WiFi)         │   │
│  │  + Button  │  │              │  │                  │   │
│  └─────┬──────┘  └──────┬───────┘  └────────┬─────────┘   │
│        │                │                    │              │
│        ▼                ▼                    ▼              │
│  ┌───────────────────────────────────────────────────┐     │
│  │          Control & Menu System                    │     │
│  │  • Menu Navigation                                │     │
│  │  • Parameter Editing                              │     │
│  │  • Real-time Graph Display                        │     │
│  │  • Button Click Handler                           │     │
│  └───────────────────────┬───────────────────────────┘     │
└────────────────────────────┼─────────────────────────────────┘
                             │ ESP-NOW
                             │ Communication
                             │
          ┌──────────────────┼──────────────────┐
          │                  │                  │
          ▼                  ▼                  ▼
    ┌─────────────┐   ┌─────────────┐   ┌─────────────┐
    │  Setpoint   │   │  PID Param  │   │  Control    │
    │  Commands   │   │  Update     │   │  ON/OFF     │
    └─────────────┘   └─────────────┘   └─────────────┘
          │                  │                  │
          └──────────────────┼──────────────────┘
                             │ ESP-NOW
                             │ Communication
                             ▼
┌─────────────────────────────────────────────────────────────┐
│                      PLANT BOARD                            │
│  ┌───────────────────────────────────────────────────┐     │
│  │          ESP-NOW RX & Data Processing             │     │
│  │  • Receive Commands                               │     │
│  │  • Update PID Parameters                          │     │
│  │  • Store to EEPROM                                │     │
│  └───────────────────────┬───────────────────────────┘     │
│                          │                                  │
│        ┌─────────────────┴─────────────────┐               │
│        │                                   │               │
│        ▼                                   ▼               │
│  ┌──────────────────┐            ┌──────────────────┐     │
│  │  DC Motor PID    │            │  AC Motor PID    │     │
│  │  Controller      │            │  Controller      │     │
│  │  • Read Encoder  │            │  • Read Encoder  │     │
│  │  • Calculate PID │            │  • Kalman Filter │     │
│  │  • PWM Output    │            │  • Calculate PID │     │
│  │                  │            │  • PWM Output    │     │
│  └────────┬─────────┘            └────────┬─────────┘     │
│           │                               │               │
│           ▼                               ▼               │
│  ┌──────────────────┐            ┌──────────────────┐     │
│  │   DC Motor       │            │   AC Motor       │     │
│  │   (Escalator)    │            │   (Conveyor)     │     │
│  │   + Encoder      │            │   + Encoder      │     │
│  └──────────────────┘            └──────────────────┘     │
│           │                               │               │
│           └───────────┬───────────────────┘               │
│                       │ Speed Data                        │
│                       │ (Real-time)                       │
│                       ▼                                   │
│  ┌───────────────────────────────────────────────────┐   │
│  │          ESP-NOW TX (Feedback)                    │   │
│  │  • Send DC RPM                                    │   │
│  │  • Send AC RPM                                    │   │
│  │  • Send Timestamp                                 │   │
│  └───────────────────────┬───────────────────────────┘   │
└────────────────────────────┼─────────────────────────────┘
                             │ ESP-NOW
                             │ Communication
                             ▼
┌─────────────────────────────────────────────────────────────┐
│                    INTERFACE BOARD                          │
│  ┌───────────────────────────────────────────────────┐     │
│  │          ESP-NOW RX (Data Reception)              │     │
│  │  • Receive Speed Data                             │     │
│  │  • Update Graph Buffer                            │     │
│  │  • Set Update Flags                               │     │
│  └───────────────────────┬───────────────────────────┘     │
│                          │                                  │
│                          ▼                                  │
│  ┌───────────────────────────────────────────────────┐     │
│  │       Real-time Graph Display Update              │     │
│  │  • Incremental Pixel Redraw                       │     │
│  │  • Oscilloscope Style                             │     │
│  │  • Setpoint Line Overlay                          │     │
│  └───────────────────────────────────────────────────┘     │
└─────────────────────────────────────────────────────────────┘
```

---

## 4. TIMING DIAGRAM

```
Time (ms):  0      50     100    150    200    250    300
            │      │      │      │      │      │      │
Plant DC:   ├──────┼──────┼──────┼──────┼──────┼──────┤
Encoder     │ Read │ Read │ Read │ Read │ Read │ Read │
Timer       │ PID  │ PID  │ PID  │ PID  │ PID  │ PID  │
(50ms)      │ TX   │ TX   │ TX   │ TX   │ TX   │ TX   │
            │      │      │      │      │      │      │
Plant AC:   ├──────┼──────┼──────┼──────┼──────┼──────┤
Encoder     │ Read │ Read │ Read │ Read │ Read │ Read │
Timer       │ PID  │ PID  │ PID  │ PID  │ PID  │ PID  │
(varies)    │ TX   │ TX   │ TX   │ TX   │ TX   │ TX   │
            │      │      │      │      │      │      │
Interface:  ├──────┼──────┼──────┼──────┼──────┼──────┤
Main Loop   │ RX   │ RX   │ RX   │ RX   │ RX   │ RX   │
(~10ms)     │Graph │Graph │Graph │Graph │Graph │Graph │
            │Input │Input │Input │Input │Input │Input │
            │      │      │      │      │      │      │
User Input: │      │      │Encoder       │      │Button│
Events      │      │      │Turn          │      │Click │
            └──────┴──────┴──────┴──────┴──────┴──────┘
```

---

## 5. STATE MACHINE DIAGRAM (Menu System)

```
                    ┌──────────────┐
                    │  INIT/SPLASH │
                    └──────┬───────┘
                           │
                           ▼
              ┌────────────────────────┐
              │     ROOT MENU          │◄──────────────┐
              │  [0] Escalator         │               │
              │  [1] Motor AC          │               │
              │  [2] WiFi Status       │               │
              └─────┬──────────┬───────┘               │
                    │          │                       │
         Select [0] │          │ Select [1]        Long Click
                    │          │                   (Back)
                    ▼          ▼                       │
      ┌──────────────────┐  ┌──────────────────┐     │
      │  ESCALATOR MENU  │  │  MOTOR AC MENU   │     │
      │  ├─[0] Graph     │  │  ├─[0] Graph     │     │
      │  └─[1] Control   │  │  └─[1] Control   │     │
      └─────┬────────┬───┘  └─────┬────────┬───┘     │
            │        │            │        │         │
    Select  │        │ Select     │        │ Select   │
    [0]     │        │ [1]        │        │          │
            │        │            │        │          │
            ▼        ▼            ▼        ▼          │
    ┌─────────┐ ┌─────────┐ ┌─────────┐ ┌─────────┐ │
    │   ESC   │ │   ESC   │ │   AC    │ │   AC    │ │
    │  GRAPH  │ │ CONTROL │ │  GRAPH  │ │ CONTROL │ │
    │         │ │         │ │         │ │         │ │
    │Real-time│ │Edit Kp, │ │Real-time│ │Edit Kp, │ │
    │Plotting │ │Ki, Kd,  │ │Plotting │ │Ki, Kd,  │ │
    │         │ │Setpoint,│ │         │ │Setpoint,│ │
    │         │ │Run/Stop │ │         │ │Run/Stop │ │
    └────┬────┘ └────┬────┘ └────┬────┘ └────┬────┘ │
         │           │           │           │       │
         │           │           │           │       │
         └───────────┴───────────┴───────────┴───────┘
                   Long Click (Back to Root)
```

---

## 6. DATA FLOW SUMMARY

### 6.1 Command Flow (Interface → Plant)
```
User Input
   ↓
Encoder/Button Detection
   ↓
Menu System Processing
   ↓
Parameter Update/Control Command
   ↓
sendTaggedFloat(typeId, value)
   ↓
ESP-NOW Transmission
   ↓
Plant Board Reception
   ↓
Parameter Update / Motor Control
   ↓
EEPROM Storage (PID parameters)
```

### 6.2 Feedback Flow (Plant → Interface)
```
Motor Running
   ↓
Encoder Interrupt (CHANGE edge)
   ↓
Timer Interrupt (50ms for DC, varies for AC)
   ↓
Pulse Count & RPM Calculation
   ↓
PID Calculation (if enabled)
   ↓
PWM Output to Motor
   ↓
sendTaggedFloat(MSG_DC_SPEED/MSG_AC_SPEED, rpm)
   ↓
ESP-NOW Transmission
   ↓
Interface Board Reception
   ↓
Update Speed History Buffer
   ↓
Set Update Flag (g_escSpeedUpdated / g_motorSpeedUpdated)
   ↓
menuUpdate() in Main Loop
   ↓
Incremental Graph Redraw
   ↓
Display Updated on TFT
```

---

## 7. KRITERIA DAN FITUR KHUSUS

### 7.1 Anti-Windup PID
- Integral term dibatasi dengan `DC_INTEGRAL_MAX/MIN` dan `AC_INTEGRAL_MAX/MIN`
- Mencegah integral overflow saat setpoint tidak tercapai
- Reset integral sum saat motor dimatikan

### 7.2 Anti-Stall Protection
- PWM minimum: DC = 800, AC = 800
- Jika output PID < minimum threshold → naikkan ke minimum
- Mencegah motor stall di output rendah

### 7.3 Kalman Filter (AC Motor)
- Smoothing pada RPM measurement
- Parameter: process_noise = 0.01, measure_noise = 3.0
- Mengurangi noise pada pembacaan encoder

### 7.4 Circular Buffer (Graph Display)
- Buffer size: 100 samples
- Oscilloscope-style incremental redraw
- Efficient memory usage

### 7.5 Persistent Storage
- PID parameters disimpan di EEPROM
- Auto-load saat restart
- Ensure parameter consistency

---

## 8. MESSAGE PROTOCOL

### 8.1 Message Format
```
┌──────────────────────┬──────────────────────┐
│  Type ID (4 bytes)   │  Value (4 bytes)     │
│  (int32_t)           │  (float)             │
└──────────────────────┴──────────────────────┘
Total: 8 bytes per message
```

### 8.2 Message Type IDs

#### DC Motor Messages (10-16):
- `10`: MSG_DC_SPEED (Plant → Interface)
- `11`: MSG_DC_KP (Interface → Plant)
- `12`: MSG_DC_KI (Interface → Plant)
- `13`: MSG_DC_KD (Interface → Plant)
- `14`: MSG_DC_Setpoint (Interface → Plant)
- `15`: MSG_DC_Control (Interface → Plant, ON/OFF)
- `16`: MSG_DC_Direction (Interface → Plant, 0/1)

#### AC Motor Messages (20-27):
- `20`: MSG_AC_SPEED (Plant → Interface)
- `21`: MSG_AC_KP (Interface → Plant)
- `22`: MSG_AC_KI (Interface → Plant)
- `23`: MSG_AC_KD (Interface → Plant)
- `24`: MSG_AC_Setpoint (Interface → Plant)
- `25`: MSG_AC_Control (Interface → Plant, ON/OFF)
- `26`: MSG_AC_Voltage (Interface → Plant)
- `27`: MSG_AC_Direction (Interface → Plant)

#### System Messages (30-100):
- `30`: MSG_PID_MODE (Interface → Plant, PID/Manual)
- `31`: MSG_SPD_REQUEST (Interface → Plant, 1=DC, 2=AC, 3=Both)
- `32`: MSG_TIMESTAMP (Plant → Interface)
- `100`: ESP_RESTART (Interface → Plant, Restart command)

---

## KESIMPULAN

Sistem ini mengimplementasikan **dual motor control** (DC dan AC) dengan:

1. **Real-time PID control** dengan anti-windup dan anti-stall
2. **Wireless communication** via ESP-NOW
3. **Interactive menu system** dengan TFT display
4. **Real-time graphing** dengan oscilloscope-style rendering
5. **Persistent parameter storage** di EEPROM
6. **Kalman filtering** untuk noise reduction (AC motor)
7. **Modular architecture** dengan separation of concerns

Kedua board bekerja secara **asynchronous** dengan komunikasi **bidirectional** untuk kontrol dan monitoring real-time.

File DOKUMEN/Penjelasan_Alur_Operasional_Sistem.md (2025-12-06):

# PENJELASAN ALUR OPERASIONAL SISTEM KONTROL MOTOR DUAL BOARD

## RINGKASAN SISTEM

Sistem ini merupakan implementasi kontrol motor ganda yang terdiri dari dua ESP (Plant Board ESP32 dan Interface Board ESP8266) yang berkomunikasi secara wireless menggunakan protokol ESP-NOW untuk mengontrol dua jenis motor: DC Motor untuk eskalator dan AC Motor untuk konveyor. Sistem ini mengintegrasikan kontrol PID real-time, monitoring visual melalui TFT display, dan penyimpanan parameter persisten di EEPROM untuk menciptakan solusi kontrol motor yang robust dan user-friendly.

---

## 1. ALUR OPERASIONAL PLANT BOARD (ESP32)

### 1.1 Inisialisasi Sistem Plant Board

Saat Plant Board dihidupkan, sistem memulai serangkaian proses inisialisasi yang terstruktur. Pertama, brownout detector dinonaktifkan untuk mencegah restart tidak terduga saat beban tinggi. Kemudian sistem menginisialisasi kontrol LED untuk indikator status, diikuti dengan setup komunikasi ESP-NOW untuk koneksi wireless dengan Interface Board. 

Setelah komunikasi siap, sistem mengakses EEPROM untuk memuat parameter PID yang telah disimpan sebelumnya. Jika ini adalah boot pertama kali (magic number tidak ditemukan di EEPROM), sistem akan menggunakan nilai default: untuk DC Motor (Kp=1.5, Ki=0.1, Kd=0.05) dan untuk AC Motor (Kp=2.0, Ki=0.08, Kd=0.04). Parameter-parameter ini kemudian disimpan ke EEPROM untuk penggunaan berikutnya.

Proses inisialisasi berlanjut dengan setup encoder untuk kedua motor. Untuk DC Motor, encoder dikonfigurasi dengan interrupt pada pin A (CHANGE edge) untuk deteksi quadrature, dan timer 50ms diaktifkan. Untuk AC Motor, prosesnya serupa namun dengan interval timer yang dapat disesuaikan. Kalman Filter juga diinisialisasi untuk AC Motor dengan parameter process_noise=0.01 dan measure_noise=3.0 untuk mengurangi noise pada pembacaan RPM.

Sebagai langkah terakhir inisialisasi, Plant Board mengirimkan semua parameter PID yang telah dimuat ke Interface Board melalui ESP-NOW, memastikan kedua board memiliki state awal yang sinkron. Setelah setup selesai, sistem memasuki main loop untuk operasi kontinu.

### 1.2 Main Loop Plant Board

Main loop Plant Board beroperasi dengan prinsip event-driven yang efisien. Loop utama terus memeriksa dua flag boolean: `dcspeedRequest` dan `acspeedRequest` yang menentukan motor mana yang aktif. Flag-flag ini diset oleh Interface Board melalui perintah ESP-NOW (MSG_SPD_REQUEST) ketika user memasuki mode Graph View pada menu.

Ketika `dcspeedRequest` bernilai TRUE, sistem mencetak data encoder DC ke serial monitor untuk debugging, kemudian memanggil fungsi `DC_ProsesPID()` untuk memproses kontrol motor DC. Proses serupa terjadi untuk AC Motor ketika `acspeedRequest` aktif, dengan pemanggilan fungsi `AC_ProsesPID()`. Loop ini berjalan terus-menerus tanpa delay blocking, memastikan respons real-time terhadap perubahan kondisi dan perintah dari Interface Board.

### 1.3 Kontrol DC Motor dengan PID

Kontrol DC Motor dijalankan melalui mekanisme timer interrupt yang dipicu setiap 50ms (DCREAD_INTERVAL). Ketika interrupt timer `DConTimer()` terpicu, sistem pertama mengecek flag `dcspeedRequest`. Jika FALSE, motor akan dimatikan dengan memanggil `DCmotorControl(0, 0)` dan flag `DCnewDataReady` di-set FALSE. Jika TRUE, flag `DCnewDataReady` di-set TRUE untuk memberi sinyal bahwa data baru siap diproses.

Di main loop, ketika flag `DCnewDataReady` terdeteksi TRUE, sistem memasuki critical section menggunakan `portENTER_CRITICAL` untuk melindungi variabel shared dari race condition. Di dalam critical section, sistem menghitung pulse count dengan mengurangi posisi encoder saat ini dengan posisi sebelumnya (`DCpulseCount = DCencoder - DClastEncoder`), kemudian menghitung RPM menggunakan formula: `DCrpm = (abs(DCpulseCount) * 60000) / (DCREAD_INTERVAL * PPR)`. Karena motor DC menggunakan gearbox dengan ratio 200:1, RPM final dihitung sebagai `DCGearboxRPM = DCrpm / 200`. Critical section kemudian ditutup dengan `portEXIT_CRITICAL`.

Setelah RPM dihitung, sistem mengecek mode operasi motor. Jika `DCMode` TRUE dan `PIDMODE` TRUE, kontrol PID dijalankan. Pertama, error dihitung sebagai selisih antara setpoint dan RPM aktual (`Error = DCsetpoint - DCGearboxRPM`). Kemudian tiga komponen PID dihitung: Proportional (`P = DCkP × Error`), Integral dengan anti-windup (`DCintegralSum += Error × dt`, dengan clamping ke DC_INTEGRAL_MAX/MIN), dan Derivative (`D = DCkD × (Error - DCpreviousError) / dt`). Output PID dihitung sebagai `output = (P + I + D) × 10`.

Output kemudian melalui saturation checking untuk mencegah overflow. Jika output > 4095, di-clamp ke 4095 (maksimal PWM 12-bit). Jika output < -4095, di-clamp ke -4095. Sistem juga mengimplementasikan anti-stall protection: jika 0 < output < 800 atau -800 < output < 0, output dinaikkan ke ±800 untuk memastikan motor mendapat torsi minimal untuk berputar.

Jika mode adalah manual (`DCMode` TRUE tapi `PIDMODE` FALSE), output PWM langsung di-map dari setpoint (0-115) ke range PWM (0-4095) tanpa perhitungan PID. Jika motor dimatikan (`DCMode` FALSE), `DCmotorControl(0, 0)` dipanggil untuk mematikan motor.

Setelah kontrol selesai, sistem mengirim feedback ke Interface Board melalui ESP-NOW: nilai `DCGearboxRPM` (MSG_DC_SPEED) dan timestamp (`millis() - waktu_awal`) untuk sinkronisasi grafik. Data juga dicetak ke serial monitor untuk monitoring dan debugging.

### 1.4 Kontrol AC Motor dengan PID dan Kalman Filter

Kontrol AC Motor memiliki kompleksitas tambahan dengan implementasi Kalman Filter untuk mengatasi noise pada pembacaan encoder. Timer interrupt `AConTimer()` bekerja dengan interval yang dapat diatur (biasanya lebih lambat dari DC untuk mengurangi beban prosesor), men-set flag `ACnewDataReady` saat `acspeedRequest` aktif.

Ketika `ACnewDataReady` TRUE di main loop, sistem memanggil fungsi `ACgetRPM()` yang mengintegrasikan Kalman Filter. Proses Kalman Filter terdiri dari empat langkah: (1) Prediction step - estimasi saat ini tetap, error covariance ditambah process noise (`AC_error_estimate += AC_process_noise`), (2) Kalman Gain calculation - menghitung bobot optimal antara estimasi dan measurement (`AC_kalman_gain = AC_error_estimate / (AC_error_estimate + AC_error_measure)`), (3) Update step - meng-update estimasi berdasarkan measurement baru (`AC_estimate += AC_kalman_gain × (measurement - AC_estimate)`), dan (4) Error covariance update (`AC_error_estimate = (1 - AC_kalman_gain) × AC_error_estimate`). Hasil akhirnya adalah `ACrpm` yang sudah difilter.

Setelah RPM filtered diperoleh, sistem memasuki critical section ISR (`portENTER_CRITICAL_ISR`) dan memanggil fungsi `AC_PID()` dengan parameter setpoint, RPM saat ini, dan delta time. Perhitungan PID dilakukan serupa dengan DC Motor: Error, Proportional, Integral dengan anti-windup (clamp ke AC_INTEGRAL_MAX/MIN), dan Derivative. Perbedaannya, output AC Motor dihitung sebagai `output = ACProportional + ACIntegral + ACDerivative` (tanpa pengali 10).

Saturation checking untuk AC Motor membatasi output ke range 0-255 (8-bit PWM) dengan anti-stall protection di threshold 800. Jika motor dimatikan (`ACMode` FALSE), tidak hanya motor dimatikan dengan `ACmotorControl(false, 0, true, 0)`, tetapi juga integral sum dan previous error direset ke 0 untuk mencegah integral windup saat motor dihidupkan kembali.

### 1.5 Komunikasi ESP-NOW di Plant Board

Plant Board berfungsi sebagai receiver untuk perintah kontrol dan transmitter untuk data feedback. Fungsi callback `OnDataReceived()` dipanggil otomatis ketika paket ESP-NOW diterima dari Interface Board. Setiap paket berukuran 8 bytes: 4 bytes untuk typeId (identifier jenis pesan) dan 4 bytes untuk value (data float).

Sistem menggunakan switch-case untuk mem-parsing typeId. Untuk parameter PID (MSG_DC_KP, MSG_DC_KI, MSG_DC_KD, MSG_AC_KP, MSG_AC_KI, MSG_AC_KD dengan typeId 11-13 dan 21-23), nilai parameter diupdate dan segera disimpan ke EEPROM menggunakan `EEPROM.put()` diikuti `EEPROM.commit()` untuk persistent storage. Untuk setpoint (MSG_DC_Setpoint typeId 14, MSG_AC_Setpoint typeId 24), nilai hanya disimpan di RAM karena bersifat runtime dan tidak perlu persisten.

Perintah kontrol motor (MSG_DC_Control typeId 15, MSG_AC_Control typeId 25) mengatur flag `DCMode` dan `ACMode` untuk menghidupkan/mematikan motor. MSG_PID_MODE (typeId 30) mengatur mode PID atau Manual untuk kedua motor. MSG_SPD_REQUEST (typeId 31) sangat penting karena menentukan motor mana yang aktif: value 1 untuk DC saja, 2 untuk AC saja, 3 untuk keduanya. Ketika speed request aktif, `waktu_awal_motor` dicatat dengan `millis()` untuk timestamp referensi.

Pesan khusus ESP_RESTART (typeId 100) memicu restart Plant Board melalui `ESP.restart()`, berguna untuk recovery dari error state atau update konfigurasi.

Untuk pengiriman data, fungsi `sendTaggedFloat()` membuat paket 8-byte dengan struktur yang sama dan mengirimkannya via `esp_now_send()` ke MAC address Interface Board. Callback `OnDataSent()` memberikan konfirmasi status pengiriman (success atau fail) untuk monitoring reliabilitas komunikasi.

---

## 2. ALUR OPERASIONAL INTERFACE BOARD (ESP8266)

### 2.1 Inisialisasi Sistem Interface Board

Interface Board memulai dengan inisialisasi serial communication pada baudrate 115200 untuk debugging. Kemudian ESP-NOW diinisialisasi untuk komunikasi dengan Plant Board, diikuti setup rotary encoder untuk input navigasi menu. Pin encoder A dan B dikonfigurasi dengan pull-up internal, dan interrupt diaktifkan pada encoder A untuk deteksi rotasi.

TFT Display ST7735 diinisialisasi dengan `tft.initR(INITR_BLACKTAB)` dan rotasi diatur ke mode 0 (portrait). Menu system kemudian diinisialisasi dengan `menuInit(&tft)` yang menampilkan splash screen selama 2 detik untuk memberikan feedback visual bahwa sistem siap. Sebagai langkah final, Interface Board mengirim perintah `ESP_RESTART` (typeId 100) ke Plant Board untuk memastikan kedua board memulai dalam state yang bersih dan sinkron.

### 2.2 Main Loop Interface Board

Main loop Interface Board mengimplementasikan polling-based input processing dengan update display yang efisien. Loop dimulai dengan menyimpan posisi encoder sebelumnya (`lastEncoder = currentEncoder`), kemudian membaca posisi saat ini dengan `DCgetEncoderCount()`. Jika posisi berubah, sistem menghitung direction (1 untuk CW, -1 untuk CCW) dan memanggil `menuNavigate(direction)` untuk menggerakkan cursor di menu atau mengubah nilai parameter jika sedang dalam mode editing.

Setelah encoder processing, sistem membaca button dengan `getButtonClick()` yang mendeteksi tiga jenis click: Single Click (press < 500ms) untuk select/confirm, Double Click (2x press dalam < 300ms) untuk toggle motor run/stop atau encoder mode, dan Long Press (hold > 1000ms) untuk back/cancel. Setiap jenis click memicu action yang berbeda sesuai context menu saat ini.

Fungsi `menuUpdate()` dipanggil di setiap iterasi loop untuk update display. Fungsi ini mengecek flag `g_escSpeedUpdated` dan `g_motorSpeedUpdated` yang di-set TRUE oleh callback ESP-NOW ketika data baru tiba. Jika flag TRUE, graph di-update dengan incremental redraw (oscilloscope style) untuk efisiensi, kemudian flag di-reset ke FALSE. Loop ditutup dengan `delay(10ms)` untuk mencegah excessive polling yang membuang-buang CPU cycles.

### 2.3 Menu Navigation System

Menu system diorganisir dalam struktur hierarki tiga level dengan state machine. Level 0 (Root Menu) berisi tiga pilihan: [0] Escalator, [1] Motor AC, dan [2] WiFi Status. Ketika user meng-select Escalator atau Motor AC, menu berpindah ke Level 1 yang berisi dua submenu: [0] Graph View untuk monitoring real-time dan [1] Control View untuk setting parameter.

Dalam Graph View, display menampilkan grafik real-time bergaya oscilloscope dengan update incremental setiap kali data baru datang dari Plant Board. Grafik menampilkan RPM motor (sumbu Y) versus waktu (sumbu X) dengan garis setpoint horizontal berwarna merah sebagai referensi target. User dapat toggle motor ON/OFF dengan double-click tanpa perlu masuk ke Control View, memberikan kontrol cepat saat monitoring.

Control View menampilkan parameter PID dan kontrol motor dalam format list. Untuk DC Motor: [0] Kp, [1] Ki, [2] Kd, [3] Setpoint (0-115 RPM), [4] Run/Stop, dan [5] Direction (Forward/Reverse). Untuk AC Motor serupa tetapi Setpoint range-nya 0-1500 RPM. User menavigasi dengan memutar encoder, single-click untuk masuk mode editing, putar encoder untuk mengubah nilai (dengan auto-increment/decrement sesuai encoder direction mode), dan single-click lagi untuk confirm dan mengirim nilai baru ke Plant Board via ESP-NOW.

Navigasi back dilakukan dengan long-press encoder button. Jika sedang editing, long-press akan cancel tanpa save perubahan. Jika di submenu (Graph atau Control View), long-press kembali ke menu parent (Escalator/Motor AC). Jika di Level 1, long-press kembali ke Root Menu. State machine memastikan transisi yang smooth dan konsisten di seluruh menu system.

### 2.4 Real-time Graph Display

Graph display mengimplementasikan rendering oscilloscope-style yang efisien dan intuitif. Area graph berukuran 118×70 pixels di TFT display, dengan sumbu X merepresentasikan waktu (scrolling dari kanan ke kiri) dan sumbu Y merepresentasikan RPM motor. Sistem menggunakan circular buffer dengan kapasitas 100 samples untuk menyimpan history data.

Ketika data speed baru diterima dari Plant Board via ESP-NOW callback `receiveData()`, nilai RPM disimpan ke circular buffer `g_escSpeedHistory[]` atau `g_motorSpeedHistory[]` dengan index yang increment secara modulo 100 (`g_escHistoryIndex = (g_escHistoryIndex + 1) % 100`). Flag `g_escSpeedUpdated` atau `g_motorSpeedUpdated` kemudian di-set TRUE untuk memberi sinyal ke main loop bahwa graph perlu update.

Di main loop, fungsi `menuUpdate()` mendeteksi flag TRUE dan memanggil `drawEscGraph()` atau `drawMotorGraph()`. Ada dua mode rendering: Full Redraw dan Incremental Update. Full Redraw dilakukan pada initial display atau ketika user berpindah menu, membersihkan area graph, menggambar border putih, menggambar garis setpoint horizontal (merah, dashed), menggambar grid waktu (vertikal cyan setiap 1 detik), dan plotting semua 100 samples dari buffer.

Incremental Update (mode normal) jauh lebih efisien: sistem menggeser semua pixel grafik 1 pixel ke kiri dengan loop yang erase pixel lama (hitam) dan redraw pixel dari kolom sebelah kanan (kuning), kemudian menggambar data terbaru di kolom paling kanan. Teknik ini menciptakan efek scrolling smooth seperti oscilloscope tanpa perlu full screen redraw, menghemat waktu render dan mengurangi flicker.

Koordinat Y dihitung dengan formula: `y = 94 - (value × 69 / MAX_VALUE)` dimana 94 adalah posisi bottom graph, 69 adalah tinggi graph area, dan MAX_VALUE adalah 115 untuk DC atau 1500 untuk AC. Hasil kemudian di-clamp ke range [25, 94] untuk memastikan pixel tetap dalam graph area. Array `escGraphY[]` dan `motorGraphY[]` menyimpan posisi Y setiap kolom untuk optimasi redraw.

### 2.5 Encoder Input Processing

Rotary encoder processing menggabungkan interrupt-driven dan polling-based approach. Encoder menggunakan quadrature encoding dengan dua signal: Channel A dan Channel B yang memiliki phase offset 90 derajat. Interrupt di-attach ke Channel A pada CHANGE edge, sehingga interrupt terpicu pada rising dan falling edge.

Di interrupt handler `DChandleEncoderA()` yang di-declare dengan attribute `IRAM_ATTR` untuk eksekusi cepat dari RAM, sistem memasuki critical section dengan `portENTER_CRITICAL_ISR(&timerMux)`, membaca state Channel A dan B, kemudian melakukan quadrature decoding: jika A rising dan B LOW atau A falling dan B HIGH, encoder bergerak forward (increment counter); sebaliknya jika A rising dan B HIGH atau A falling dan B LOW, encoder bergerak backward (decrement counter). Critical section ditutup dengan `portEXIT_CRITICAL_ISR(&timerMux)` untuk release mutex.

Di main loop, sistem polling encoder count dengan membandingkan `currentEncoder` dengan `lastEncoder`. Jika berbeda, direction dihitung (1 atau -1), dan action dilakukan tergantung mode: jika `g_isEditing` TRUE (sedang edit parameter), nilai parameter diubah sesuai direction dan `encoderMode` (ENCODER_UP untuk increment, ENCODER_DOWN untuk decrement); jika `g_isEditing` FALSE, `menuNavigate(direction)` dipanggil untuk scroll menu.

Button encoder diproses dengan debouncing dan multi-click detection. State button dibaca dengan `digitalRead()`, kemudian algoritma timing-based mendeteksi: Single Click (press duration < 500ms, release, tidak ada second click dalam 300ms), Double Click (press-release-press sequence dalam < 300ms total), dan Long Press (press duration > 1000ms). Setiap jenis click men-trigger action berbeda sesuai context menu yang sesuai.

Fitur `toggleEncoderMode()` dipanggil saat double-click di non-graph context, membalik arah increment/decrement encoder. Ini berguna saat editing parameter: user bisa cepat switch antara "putar kanan = naik" dan "putar kanan = turun" sesuai preferensi, meningkatkan ergonomics terutama saat fine-tuning parameter PID.

### 2.6 Komunikasi ESP-NOW di Interface Board

Interface Board berfungsi sebagai master controller yang mengirim perintah dan menerima feedback data. Callback `receiveData()` mem-parsing paket 8-byte ESP-NOW sama seperti di Plant Board. Untuk message type MSG_DC_SPEED (typeId 10) dan MSG_AC_SPEED (typeId 20), nilai RPM di-extract dan fungsi `updateEscalatorSpeed()` atau `updateMotorSpeed()` dipanggil.

Fungsi update speed melakukan tiga hal: (1) menyimpan nilai ke circular buffer history untuk graphing, (2) meng-update variabel `g_escSpeed` atau `g_motorSpeed` untuk display numerik, dan (3) men-set flag `g_escSpeedUpdated` atau `g_motorSpeedUpdated` TRUE untuk trigger graph redraw di main loop. Flag `g_escConnected` dan `g_motorConnected` juga di-set TRUE untuk indikator status koneksi ESP-NOW.

Message type parameter PID (MSG_DC_KP hingga MSG_DC_KD dan MSG_AC_KP hingga MSG_AC_KD) diterima sebagai echo confirmation dari Plant Board. Nilai parameter di-update di Interface Board untuk menjaga sinkronisasi display dengan actual value di Plant Board. MSG_TIMESTAMP (typeId 32) diterima dan disimpan ke timestamp buffer untuk sinkronisasi waktu pada graph axis.

Untuk pengiriman perintah, fungsi `sendTaggedFloat()` dipanggil dari berbagai tempat di menu system. Saat user mengubah parameter PID, fungsi ini dipanggil dengan typeId yang sesuai (contoh: `sendTaggedFloat(MSG_DC_KP, g_dcKp)`). Saat toggle motor ON/OFF, `sendTaggedFloat(MSG_DC_Control, g_escRunning ? 1.0 : 0.0)` dikirim. Saat masuk Graph View, `sendTaggedFloat(MSG_SPD_REQUEST, requestValue)` dikirim untuk mengaktifkan data streaming dari Plant Board.

Callback `onDataSent()` memberikan feedback status pengiriman. Jika status adalah `ESP_NOW_SEND_SUCCESS`, log dicetak ke serial. Jika fail, error dicatat dan flag `g_espnowInit` bisa di-reset FALSE untuk trigger reconnection attempt. Reliable delivery ESP-NOW memastikan command critical tidak hilang dalam transmisi wireless.

---

## 3. INTERAKSI SISTEM SECARA KESELURUHAN

### 3.1 Skenario Operasional: User Mengubah Setpoint DC Motor

Proses dimulai ketika user menavigasi ke menu Escalator > Control View menggunakan rotary encoder. User scroll dengan memutar encoder hingga highlight berada di "Setpoint", kemudian single-click untuk masuk mode editing. Indikator visual (misalnya warna atau border berkedip) muncul di display menunjukkan parameter sedang di-edit.

User memutar encoder untuk mengubah nilai setpoint dari, misalnya, 50 RPM ke 80 RPM. Setiap detent rotasi encoder mengubah nilai dengan increment tertentu (misalnya ±1 atau ±5 tergantung range). Display real-time menampilkan nilai baru saat encoder diputar. User kemudian single-click lagi untuk confirm perubahan.

Saat confirm, Interface Board memanggil `sendTaggedFloat(MSG_DC_Setpoint, 80.0)` yang membuat paket 8-byte: `[0x00, 0x00, 0x00, 0x0E]` (typeId 14 untuk MSG_DC_Setpoint) + `[0x42, 0xA0, 0x00, 0x00]` (float 80.0 dalam IEEE 754). Paket dikirim via ESP-NOW dengan latency typical < 10ms.

Di Plant Board, callback `OnDataReceived()` terpicu, mem-parsing typeId 14, meng-extract value 80.0, dan meng-update variabel `DCsetpoint = 80.0`. Nilai ini langsung aktif untuk PID calculation di interrupt timer berikutnya. Pada interrupt cycle berikutnya (50ms), PID controller menghitung error baru (`Error = 80.0 - DCGearboxRPM`), melakukan kalkulasi P, I, D, dan menghasilkan output PWM yang lebih tinggi untuk mempercepat motor mencapai setpoint baru.

Saat motor mempercepat, encoder Plant Board mendeteksi kenaikan RPM. Data RPM baru dikirim kembali ke Interface Board via `sendTaggedFloat(MSG_DC_SPEED, DCGearboxRPM)` setiap 50ms. Interface Board menerima update speed, menyimpannya ke buffer history, dan graph di-update secara incremental, menampilkan kurva RPM yang naik menuju garis setpoint baru (80 RPM). User dapat melihat response real-time system terhadap perubahan setpoint, termasuk overshoot, settling time, dan steady-state error yang menunjukkan kualitas tuning PID.

### 3.2 Skenario Operasional: User Melakukan Tuning PID

User ingin melakukan fine-tuning parameter PID DC Motor untuk mendapatkan response optimal. Prosesnya dimulai dengan navigasi ke Escalator > Control View, kemudian scroll ke parameter Kp. User single-click untuk edit, ubah nilai dari 1.5 ke 2.0 dengan memutar encoder, kemudian single-click untuk confirm. Interface Board mengirim `sendTaggedFloat(MSG_DC_KP, 2.0)` ke Plant Board.

Plant Board menerima pesan, meng-update `DCkP = 2.0`, dan yang krusial, menyimpan nilai baru ke EEPROM dengan sequence: `EEPROM.put(ADDRESS_DC_KP, DCkP)` diikuti `EEPROM.commit()`. Proses write ke EEPROM memakan waktu beberapa milliseconds, tetapi dilakukan secara non-blocking sehingga tidak mengganggu timer interrupt dan kontrol motor. Serial monitor mencetak konfirmasi: "DC Kp updated to 2.0 and saved to EEPROM".

User kemudian melakukan hal serupa untuk Ki dan Kd. Setelah semua parameter baru tersimpan, user berpindah ke Graph View untuk observe behavior motor dengan parameter baru. Double-click pada encoder untuk toggle motor ON. Motor start dan Interface Board mengirim `sendTaggedFloat(MSG_DC_Control, 1.0)` serta `sendTaggedFloat(MSG_SPD_REQUEST, 1.0)` untuk activate DC motor dan request speed data streaming.

Plant Board menerima control command, men-set `DCMode = TRUE`, dan motor mulai berputar dengan PID control menggunakan parameter baru. Data speed streaming dimulai, dan graph di Interface Board menampilkan response transient: user dapat observe rise time, overshoot percentage, settling time, dan steady-state behavior. Jika response tidak memuaskan (misalnya overshoot terlalu besar), user bisa kembali ke Control View, adjust Kp lebih rendah atau tingkatkan Kd, dan repeat prosesnya hingga mendapat tuning optimal.

Ketika Plant Board di-restart (power cycle atau perintah ESP_RESTART), setup routine membaca EEPROM, menemukan magic number valid (0x12345678), dan load semua parameter PID yang telah disimpan, termasuk Kp, Ki, Kd yang baru. Ini memastikan tuning user tidak hilang dan motor langsung beroperasi dengan parameter optimal tanpa perlu re-tuning setiap restart.

### 3.3 Skenario Operasional: Monitoring Dual Motor Simultaneous

User ingin memonitor kedua motor secara bersamaan untuk observe interaksi atau compare performance. Dari Root Menu, user select Escalator dan otomatis masuk Graph View untuk DC Motor. Graph menampilkan RPM DC Motor real-time. User kemudian long-press untuk back ke Root Menu, select Motor AC, dan masuk Graph View AC Motor.

Untuk monitoring kedua motor sekaligus, user perlu mengatur agar Interface Board request data dari kedua motor. Ini dilakukan dengan mengirim `sendTaggedFloat(MSG_SPD_REQUEST, 3.0)` dimana value 3 berarti "request both DC and AC". Plant Board mem-parsing value 3, men-set `dcspeedRequest = TRUE` dan `acspeedRequest = TRUE`, sehingga kedua motor mulai streaming data.

Di Plant Board, timer interrupt DC (50ms) dan AC (varies) berjalan independent. Setiap timer terpicu, kalkulasi PID dilakukan, motor dikontrol, dan data RPM dikirim via ESP-NOW dengan typeId berbeda: MSG_DC_SPEED (10) untuk DC dan MSG_AC_SPEED (20) untuk AC. Paket-paket ini dikirim asynchronous tanpa blocking satu sama lain.

Interface Board menerima kedua stream data via callback yang sama `receiveData()`. Callback mem-parsing typeId untuk menentukan data mana yang update: jika typeId 10, update DC buffer dan set flag `g_escSpeedUpdated`; jika typeId 20, update AC buffer dan set flag `g_motorSpeedUpdated`. Main loop kemudian update kedua graph sesuai context menu yang ditampilkan.

User bisa toggle antar Graph View DC dan AC dengan navigasi menu untuk compare secara visual bagaimana kedua motor respond terhadap setpoint changes, load disturbances, atau parameter tuning. Timestamp yang dikirim via MSG_TIMESTAMP memastikan data dari kedua motor ter-sinkronisasi secara temporal, memungkinkan analisis timing-critical jika ada interdependensi antara eskalator (DC) dan konveyor (AC) dalam aplikasi real-world.

### 3.4 Failure Scenarios dan Recovery Mechanisms

Sistem didesain robust dengan beberapa failure recovery mechanisms. Jika koneksi ESP-NOW terputus (misalnya karena interference atau jarak terlalu jauh), Plant Board mendeteksi tidak ada speed request dalam periode tertentu dan automatic mematikan motor sebagai safety feature. Interface Board mendeteksi tidak ada data incoming, men-reset flag `g_escConnected` dan `g_motorConnected` ke FALSE, dan menampilkan indikator "Connection Lost" di display.

User dapat memicu reconnection dengan long-press encoder untuk back ke Root Menu kemudian re-enter Graph View, atau dengan mengirim ESP_RESTART command yang me-restart Plant Board dan re-inisialisasi ESP-NOW. Setelah reconnect, kedua board exchange MAC address lagi dan komunikasi resume normal.

Jika EEPROM corrupt (misalnya power loss during write), Plant Board mendeteksi magic number invalid saat boot, load default parameters, dan menulis magic number baru ke EEPROM beserta default values. Serial monitor mencetak warning "EEPROM corrupted, loading defaults", memberi informasi ke developer atau technician bahwa re-tuning mungkin diperlukan.

Jika motor stall atau load berlebih, anti-stall protection mechanism di PID controller memastikan PWM minimal 800 selalu applied, mencegah motor stuck di torsi rendah. Jika stall persist, user dapat observe di graph bahwa RPM tidak naik meskipun PWM high, indicating mechanical problem atau load terlalu berat. User kemudian bisa lower setpoint atau investigate mechanical issue.

Brownout protection dinonaktifkan di Plant Board untuk prevent false restart saat motor draw high current pada startup. Namun jika voltage drop terlalu severe (below brownout threshold despite disable attempt), ESP akan inevitably reset, tetapi setelah boot akan automatic load PID parameters dari EEPROM dan resume operation with minimal disruption.

---

## 4. KEUNGGULAN ARSITEKTUR SISTEM

### 4.1 Separation of Concerns

Sistem mengimplementasikan clean separation antara control logic (Plant Board) dan user interface (Interface Board). Plant Board fokus pada real-time control: PID calculation, motor driving, encoder reading, dan sensor fusion (Kalman Filter). Interface Board fokus pada human-machine interaction: menu navigation, display rendering, input processing, dan data visualization. Pemisahan ini memungkinkan optimasi independent: Plant Board bisa run PID loop di fixed-rate timer interrupt tanpa terganggu UI rendering, sementara Interface Board bisa implement complex menu logic dan graph animation tanpa jitter timing-critical control loop.

### 4.2 Real-time Performance dengan Reliability

Penggunaan timer interrupt dan ISR (Interrupt Service Routine) memastikan PID control berjalan deterministic dengan timing presisi. DC Motor di-control setiap exact 50ms, AC Motor sesuai configured interval. Critical section protection (`portENTER_CRITICAL`) mencegah race condition pada shared variable antara ISR dan main task. Kalman Filter mengurangi measurement noise, meningkatkan stability control loop terutama untuk AC Motor yang lebih susceptible terhadap electrical noise.

ESP-NOW dipilih untuk komunikasi karena low latency (< 10ms typical), tanpa overhead TCP/IP stack, dan reliable delivery dengan ACK mechanism. Bandwidth cukup untuk streaming 20 Hz (50ms interval) data speed plus occasional parameter updates tanpa congestion.

### 4.3 User Experience dan Usability

Interface Board menyediakan intuitive graphical interface yang menampilkan real-time system behavior. Oscilloscope-style graph dengan scrolling animation memberikan feedback visual yang powerful untuk understand system dynamics. User bisa langsung see cause-effect relationship: adjust Kp → observe overshoot increase, adjust Kd → see damping improve.

Multi-click detection pada encoder button (single/double/long) memaksimalkan single input device untuk multiple functions, reducing hardware complexity. Hierarchical menu structure dengan logical grouping (motor selection → view selection → parameter selection) matches user mental model dan minimizes navigation steps.

### 4.4 Persistent Configuration dan Maintenance-Free

PID parameters disimpan di EEPROM dengan magic number validation memastikan configuration persist across power cycles. Technician bisa tune system once di commissioning phase, dan tuning tersebut retained forever. Jika parameter needs adjustment during maintenance, changes bisa dilakukan via GUI (Interface Board) dan automatic saved tanpa perlu USB cable atau programming tools.

Dual-board architecture juga memudahkan maintenance: jika Interface Board rusak (display crack, encoder wear out), Plant Board tetap bisa operate standalone dengan last known parameters. Sebaliknya, jika Plant Board perlu replacement, Interface Board bisa send parameters via ESP-NOW untuk configure replacement board automatically.

### 4.5 Scalability dan Extensibility

Arsitektur message-passing dengan typed protocol (typeId system) memudahkan extension. Untuk menambah motor ketiga, cukup define new message types (MSG_MOTOR3_KP, MSG_MOTOR3_SPEED, etc.) dan implement handler di callback. Menu system bisa di-extend dengan menambah menu item baru tanpa refactor existing code.

Circular buffer dan incremental rendering untuk graph bisa scale ke multiple concurrent graphs dengan memory footprint predictable. Jika future requirement perlu display kedua motor di split-screen, architecture sudah support karena update mechanism per-motor sudah independent dengan flag system (`g_escSpeedUpdated` vs `g_motorSpeedUpdated`).

---

## KESIMPULAN

Sistem kontrol motor dual-board ini merepresentasikan implementasi industrial-grade embedded system dengan fokus pada real-time performance, reliability, dan usability. Plant Board ESP32 menjalankan deterministic control loop dengan PID algorithm yang dilengkapi anti-windup, anti-stall protection, dan Kalman filtering untuk robust operation. Interface Board ESP8266 menyediakan rich user interface dengan graphical feedback, intuitive navigation, dan comprehensive parameter configuration capabilities.

Komunikasi wireless ESP-NOW memungkinkan kedua board beroperasi dengan loose coupling, meningkatkan reliability (isolated failure) dan flexibility (physical separation). Persistent storage di EEPROM memastikan configuration stability across operational lifecycle. Architecture yang modular dan message-oriented memudahkan maintenance, debugging, dan future enhancement.

Sistem ini cocok untuk aplikasi industrial automation seperti conveyor systems, escalators, material handling, atau automated production lines dimana dual motor coordination, precise speed control, real-time monitoring, dan ease of parameter tuning menjadi critical requirements.

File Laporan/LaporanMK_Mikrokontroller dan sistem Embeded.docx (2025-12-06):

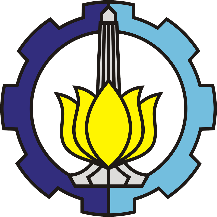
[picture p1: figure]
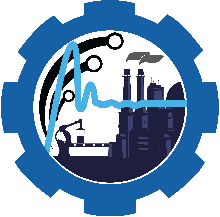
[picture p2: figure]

Laporan Project Based Learning Mata Kuliah

VE230310-Mikroprosesor dan Sistem Embedded

Semester Ganjil 2025/2026

SISTEM KONTROL SEDERHANA

Eskalator Mini Motor DC dengan Kendali ESP32 menggunakan Kontrol PID

Disusun oleh:

Abednego Tegar Imanto

NRP 2040241099

Program Studi Sarjana Terapan Teknologi Rekayasa Otomasi

Departemen Teknik Elektro Otomasi

Fakultas Vokasi

Institut Teknologi Sepuluh Nopember

Desember 2025

DAFTAR ISI

# RINGKASAN

Tujuan utama dari penyusunan laporan ini adalah untuk memahami secara mendalam korelasi antara mata kuliah Mikroprosesor dan Sistem Embedded dengan bentuk pembelajaran Project-Based Learning (PjBL), khususnya project pembuatan sistem kontrol kecepatan motor menggunakan metode PID yang pada project ini dikendalikan menggunakan mikrokontroller ESP32 yang diberikan kepada mahasiswa semester 3. Pada project ini implementasi dari metode kontrol PID berupa sistem eskalator dimana nantinya akan dikendalikan oleh Plant Board berbasis ESP32 dan Interface Board berbasis ESP8266. Kedua Board ini akan saling berkomunikasi untuk mengatur dan menampilkan jalannya sistem motor AC maupun Motor DC menggunakan protokol ESP-NOW

Melalui PjBL, mahasiswa diharapkan tidak hanya memperoleh pemahaman dari sisi teori yang disampaikan di kelas, tetapi juga mampu menerapkan konsep-konsep tersebut dalam praktik nyata melalui kegiatan perancangan dan implementasi sistem kontrol.Dengan melakukan analisis terhadap hubungan antara materi perkuliahan dan project yang dikerjakan, mahasiswa dapat melihat lebih jelas bagaimana konsep yang dipelajari memiliki peran penting dalam penyelesaian permasalahan teknis dalam pengerjaan project. Selain itu, kegiatan ini juga bertujuan untuk meningkatkan pemahaman mahasiswa mengenai fungsi dan manfaat setiap topik dalam mata kuliah Mikroprosesor dan Sistem Embedded, sehingga mereka mampu mengaitkan teori yang diperoleh dengan aplikasi praktis dalam bidang kontrol dan instrumentasi. Melalui proses tersebut, mahasiswa dapat mengembangkan kompetensi teknis, pemecahan masalah, serta keterampilan analitis yang diperlukan dalam dunia industri.

Kata Kunci: PjBL, ESP, Kontrol PID

# PENDAHULUAN

## I.1 Deskripsi Project

Proyek ini disusun dalam Penugasan Project Based Learning (PjBL), dengan tujuan mengintegrasikan teori yang telah dipelajari ke dalam sebuah implementasi yang nyata. Model pembelajaran ini mendorong mahasiswa untuk tidak hanya memahami konsep, tetapi juga mampu mengaplikasikannya dalam bentuk sistem yang dapat diuji dan dianalisis secara langsung.

Dalam hal ini, proyek yang dipilih adalah pembuatan eskalator mini berbasis minimum system mikrokontroler ESP32 dengan kontrol PID sebagai pengendali utama seperti yang ditunjukkan pada Gambar 1. Penggunaan kontrol PID penting karena mampu memberikan respons yang lebih stabil, presisi, dan Responsif terhadap perubahan beban maupun kecepatan pada sistem. Dengan demikian, eskalator mini dapat beroperasi secara lebih realistis dan menyerupai karakteristik sistem industri yang sebenarnya.

ESP32 dipilih karena kami ingin menggunakan mikrokontroller dengan kecepatan komputasi yang cukup kencang dengan banyak pin I/O serta memiliki fitur wifi di dalamnya. Wifi pada mikrokontroller ini nantinya akan digunakan sebagai media komunikasi antar device yaitu antara plant board dengan interface board menggunakan protokol komunikasi ESP-NOW. Seperti pada Gambar 2. Sementara itu ESP8266 dipilih karena harganya murah namun tetap mampu berkomunikasi secara wireless menggunakan wifi dan karena pada interface board ini akan difungsikan sebagai tampilan saja dan tidak melakukan komputasi yang tinggi dan tidak butuh banyak pin I/O . Pada plant board mikrokontroller difokuskan untuk mengatur segala jenis sensor dan aktuator pada area PLANT yaitu meliputi pengendalian motor DC (driver mosfet, encoder) serta pengendalian motor AC (ADC, DAC), Sementara itu Interface Board yang berbasis ESP8266. mengatur tampilan pada LCD yang menu menu nya diatur melalui Rotary encoder dan menampilkan data kecepatan dan parameter lainnya yang dikirm oleh PLANT melalui komunikasi ESP-NOW. Jumlah pin I/O yang cukup banyak pada keseluruhan sistem dan interval pemrosesan kontrol motor yang tinggi (50ms) dapat membebani kinerja dari mikrokontroller, sehingga akan menyebabkan Crash maupun delay pada mikrokontroller pada saat menjalankan program. Oleh karena itu digunakanlah 2 board ESP supaya setiap ESP berfokus mengerjakan task nya tanpa ada tambahan tugas lain.

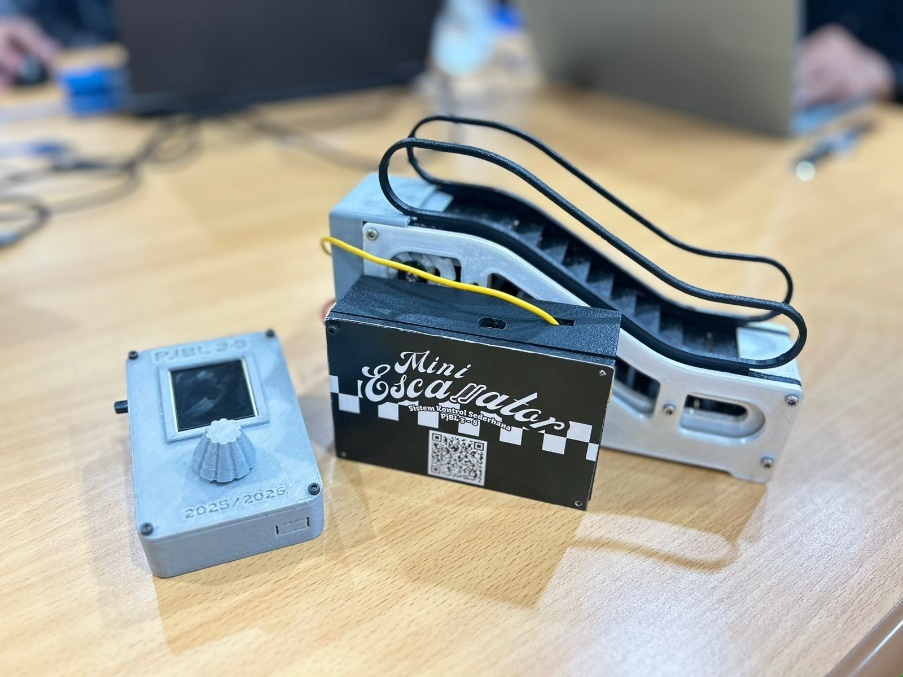
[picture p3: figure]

Gambar 1 desain Ekskalator

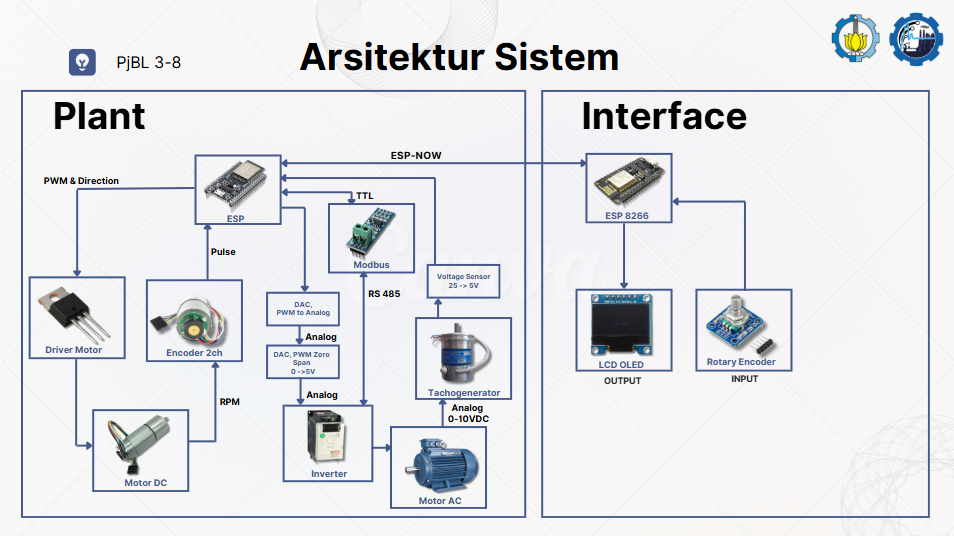
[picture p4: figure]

Gambar 2 Arsitektur Sistem

## I.2 Tujuan

Mahasiswa mampu merancang keseluruhan sistem yang minimal harus terdiri atas:

1. Perangkat keras kontroler: Sistem Minimum Mikrokontroler ESP32

2. Metode Kontrol yang diimplementasikan pada program mikrokontroler (PID)

3. Sensor pembaca kecepatan motor AC maupun DC

4. Modul Input/Output untuk menghubungkan dari modul kontroler ke plant

5. Plant Motor DC dan Driver

6. Plant Motor AC dan Inverter/VFD (disediakan oleh departemen)

7. 3D Desain Plant

# MATERI MATA KULIAH MIKROPROSESOR DAN SISTEM EMBEDDED

## II.1 Deskripsi Mata Kuliah

Mata kuliah Mikroprosesor dan Sistem Embedded merupakan mata kuliah yang termasuk dalam rumpun keilmuan Mikroelektronika dan Komputasi. Mata kuliah ini mensyaratkan pemahaman sebelumnya pada mata kuliah Algoritma dan Pemrograman serta Rangkaian Elektronika.Secara garis besar, mata kuliah ini bertujuan memberikan pemahaman mendalam mengenai arsitektur dasar mikroprosesor dan perancangan sistem minimum berbasis mikrokontroler. Ruang lingkup materi meliputi pembahasan teknis mengenai Set Instruksi Mesin, Antarmuka I/O (Input/Output), Unit Pemrosesan Dasar, serta manajemen sistem memori. Mahasiswa akan mempelajari arsitektur komputer tingkat lanjut, khususnya sistem embedded berbasis ARM Cortex-M, yang mencakup manajemen thread, manajemen waktu, sistem Real-Time, antarmuka berkecepatan tinggi (High-Speed Interfacing), hingga manajemen sistem berkas.

Dalam aspek praktit, mahasiswa dituntut untuk mampu merancang, mengonfigurasi, dan menganalisis sistem menggunakan periferal mikrokontroler seperti ADC, PWM, Komunikasi Serial, Timer, Counter, dan Interupsi guna menyelesaikan permasalahan keteknikan sederhana. Proses pembelajaran didukung oleh penggunaan perangkat lunak simulasi dan pengembangan seperti Proteus, Arduino IDE, dan STM32CubeIDE

## II.2 Materi Perkuliahan

### II.2.1 Dasar Mikroprosesor dan Arsitektur

1. Konsep Dasar, Sejarah, dan Sistem Bilangan Mikroprosesor
2. Arsitektur Mikroprosesor dan Unit Pemrosesan Dasar
3. Antarmuka Input/Output ($I/O$) Dasar

### II.2.2 Set Instruksi dan Sistem Memori

1. Set Instruksi Mesin: Data Movement, Aritmatik, dan Logika
2. Sistem Memori: Mode Pengalamatan Data, Program Memory, dan Stack Memory

### II.2.3 Mikrokontroler dan Antarmuka Periferal

1. Dasar dan Arsitektur Mikrokontroler
2. Digital $I/O$, Liquid Crystal Display (LCD), Analog-to-Digital Converter (ADC), dan Pulse Width Modulation (PWM)
3. Komunikasi Serial (Metode SPI, I2C, UART)
4. Timer, Counter, dan Manajemen Interupsi

### II.2.4 Arsitektur Lanjut dan Sistem Embedded (ARM Cortex-M)

1. Pengenalan Arsitektur Komputer dan Sistem Embedded ARM Cortex-M
2. Konfigurasi $I/O$ Development Board ARM Cortex-M (Paralel $I/O$, Transmisi Sinkron) ¹²¹²

### II.2.5 Real-Time Operating System (RTOS) dan Manajemen Sistem

1. Manajemen Thread: Function Pointer, Semaphore, Sinkronisasi Thread, dan Manajemen Proses
2. Manajemen Waktu dan Sistem Real-Time (Penjadwalan Prioritas)
3. Antarmuka High-Speed: Hardware FIFO, Dual Port Memory, dan Direct Memory Access (DMA)
4. Manajemen Sistem File: Alokasi Sistem File, Simple File System, dan Sistem Readers-Writers

## II.3 Pembahasan Materi

### II.3.1 Dasar Mikroprosesor dan Arsitektur

Mikroprosesor merupakan unit pemrosesan pusat (Central Processing Unit/CPU) yang dikemas dalam satu sirkuit terintegrasi (Integrated Circuit). Secara fundamental, mikroprosesor berfungsi sebagai otak dari sistem komputer yang bertugas mengambil instruksi, menerjemahkan kode, dan mengeksekusi operasi aritmatika serta logika.

Pemahaman mengenai sistem bilangan (biner dan heksadesimal) menjadi fondasi utama karena mikroprosesor beroperasi menggunakan logika digital basis dua.

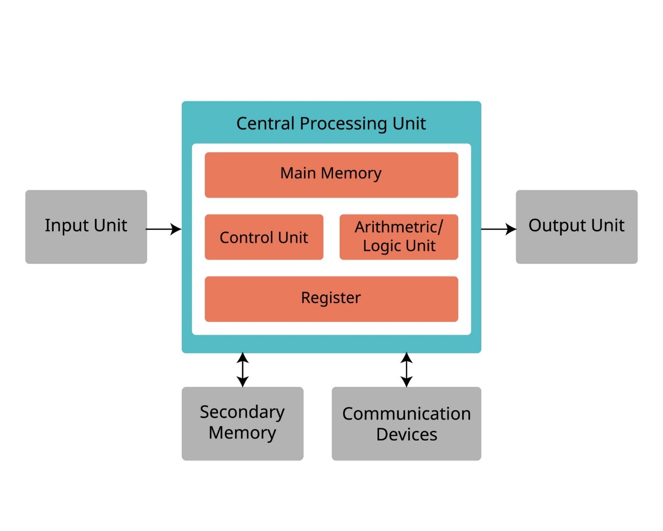
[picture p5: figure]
Image of Von Neumann vs Harvard Architecture diagram

Dalam arsitekturnya, terdapat dua model utama yang sering digunakan, yaitu Von Neumann (di mana data dan instruksi berbagi bus yang sama) dan Harvard (di mana data dan instruksi memiliki jalur bus terpisah). Unit pemrosesan dasar dalam mikroprosesor terdiri dari Arithmetic Logic Unit (ALU), Control Unit (CU), dan Register yang bekerja secara sinkron untuk menjalankan siklus instruksi fetch-decode-execute.

### II.3.2 Set Instruksi dan Sistem Memori

Agar mikroprosesor dapat bekerja, diperlukan sekumpulan perintah standar yang disebut Instruction Set Architecture (ISA). Instruksi ini dikategorikan menjadi beberapa jenis utama:

- Data Movement: Instruksi untuk memindahkan data antar register atau antara memori dan register (contoh: LOAD, STORE, MOVE).
- Aritmatik dan Logika: Instruksi untuk operasi matematika (ADD, SUB) dan manipulasi logika bit (AND, OR, XOR).

Sistem memori memegang peranan krusial dalam penyimpanan instruksi dan data sementara. Konsep pengalamatan (addressing modes) menentukan bagaimana operand instruksi diakses, baik secara langsung (immediate), langsung ke alamat (direct), maupun tidak langsung (indirect). Selain itu, pemahaman mengenai Stack Memory sangat penting untuk manajemen sub-rutin dan penyimpanan variabel lokal yang bersifat LIFO (Last In, First Out).

### II.3.3 Mikrokontroler dan Antarmuka Periferal

Berbeda dengan mikroprosesor yang hanya berupa CPU, mikrokontroler adalah sistem komputer lengkap dalam satu chip (System on Chip) yang mencakup CPU, memori (RAM/ROM), dan periferal Input/Output (I/O).

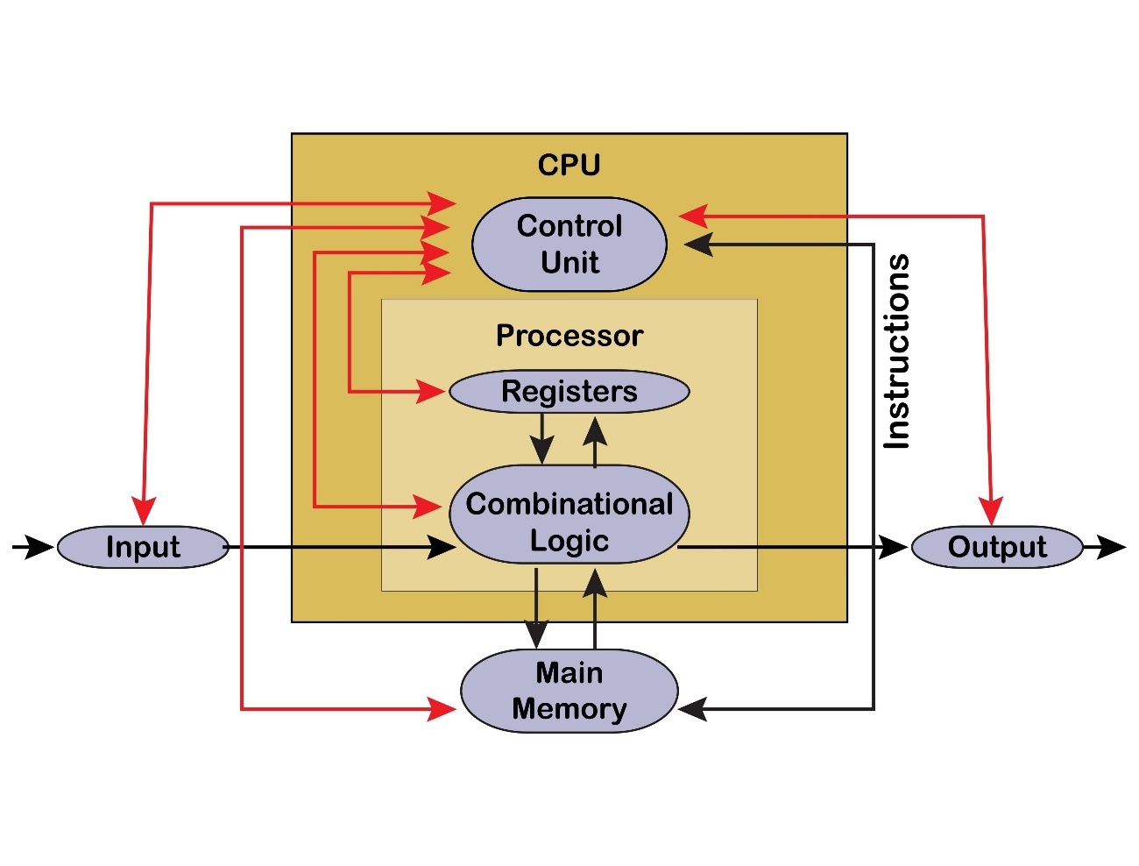
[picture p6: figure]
Image of Microcontroller Block Diagram

Fitur-fitur utama yang dipelajari meliputi:

1. Digital I/O & ADC: Pin digital digunakan untuk kontrol logika (High/Low), sedangkan Analog-to-Digital Converter (ADC) berfungsi mengonversi sinyal analog fisik (seperti suhu atau cahaya) menjadi nilai digital agar dapat diproses CPU.
2. PWM (Pulse Width Modulation): Teknik modulasi lebar pulsa untuk mensimulasikan keluaran analog, sering digunakan untuk pengaturan kecepatan motor DC atau intensitas lampu LED.
3. Komunikasi Serial: Protokol standar untuk pertukaran data antar perangkat. Meliputi UART (asinkron), SPI (sinkron kecepatan tinggi), dan I2C (sinkron dua kawat).
4. Timer & Interupsi: Timer digunakan untuk penghitungan waktu presisi, sedangkan interupsi memungkinkan mikrokontroler merespons kejadian eksternal mendesak dengan menghentikan sementara program utama, meningkatkan efisiensi dibanding metode polling.

### II.3.4 Arsitektur Lanjut dan Sistem Embedded (ARM Cortex-M)

Materi ini beralih ke arsitektur 32-bit modern menggunakan prosesor ARM Cortex-M yang menjadi standar industri sistem embedded saat ini. Berbeda dengan mikrokontroler 8-bit konvensional, ARM Cortex-M menawarkan efisiensi daya yang lebih baik dan kinerja komputasi yang tinggi.

Pengembangan sistem pada platform ini melibatkan konfigurasi periferal yang lebih kompleks, seperti antarmuka paralel berkecepatan tinggi dan transmisi sinkron yang memerlukan pemahaman mendalam tentang clock tree dan manajemen daya pada mikrokontroler.

### II.3.5 Real-Time Operating System (RTOS) dan Manajemen Sistem

Pada tingkat lanjut, sistem embedded tidak lagi hanya berjalan secara prosedural ("bare metal"), melainkan menggunakan sistem operasi waktu nyata (RTOS).

Poin-poin krusial dalam implementasi RTOS meliputi:

Manajemen Thread: Pembagian program menjadi tugas-tugas kecil Dalam meninjau laporan ini, terdapat beberapa bagian yang dapat dipersingkat agar isi laporan menjadi lebih ringkas dan mudah dipahami. Berikut adalah beberapa saran untuk memperpendek laporan tersebut:

## II.4 1. Ringkasan Eksekutif

Bagian ini dapat dipadatkan dengan menghilangkan detail yang kurang penting dan fokus pada poin utama. Misalnya, alih-alih menjelaskan secara rinci setiap temuan, cukup sampaikan hasil utama dan rekomendasi utama.

## II.5 2. Data dan Statistik

Data yang terlalu rinci dapat disajikan dalam bentuk tabel yang ringkas atau grafik. Penjelasan yang berlebihan tentang angka-angka tertentu bisa disederhanakan, misalnya dengan menyebutkan tren umum daripada angka spesifik yang tidak terlalu penting.

## II.6 3. Metodologi

Bagian ini seringkali dapat dipersingkat dengan menyampaikan metode utama yang digunakan tanpa perlu menjelaskan setiap langkah secara detail, kecuali jika sangat relevan untuk pemahaman laporan.

## II.7 4. Analisis

Analisis yang panjang dapat diringkas dengan menyoroti poin-poin utama dan mengeliminasi penjelasan yang berulang atau tidak esensial. Gunakan poin-poin bullet untuk menyampaikan analisis secara ringkas dan jelas.

## II.8 5. Kesimpulan dan Rekomendasi

Kesimpulan harus langsung ke poin utama tanpa pengulangan informasi yang sudah disampaikan sebelumnya. Rekomendasi juga harus disusun secara singkat dan padat, fokus pada langkah-langkah penting yang harus diambil.

Dengan melakukan pemDalam meninjau laporan ini, terdapat beberapa bagian yang dapat dipersingkat agar laporan menjadi lebih ringkas dan mudah dipahami. Berikut adalah beberapa saran untuk memperpendek isi laporan:

- Ringkasan Data Utama: Fokus pada data dan statistik penting yang mendukung inti laporan, dan hilangkan detail yang kurang relevan.
- Penggunaan Kalimat Efisien: Ubah kalimat panjang menjadi kalimat yang lebih singkat dan langsung ke poin utama tanpa mengurangi makna.
- Penghapusan Redundansi: Periksa bagian yang mengulang informasi yang sama dan hapus pengulangan tersebut.
- Penggunaan Poin-Poin: Uraikan informasi penting dalam bentuk poin-poin agar lebih mudah dibaca dan dipahami.
- Pengurangan Detail Teknis: Jika laporan berisi penjelasan teknis yang terlalu mendalam, pertimbangkan untuk menyederhanakan atau merangkum bagian tersebut.
- Dengan melakukan langkah-langkah tersebut, laporan akan menjadi lebih ringkas tanpa kehilangan informasi penting, sehingga pembaca dapat memahami inti laporan dengan lebih cepat dan efisien.angkasan pada bagian-bagian tersebut, laporan akan menjadi lebih ringkas, padat, dan tetap informatif. Hal ini akan memudahkan pembaca dalam memahami inti laporan tanpa harus membaca seluruh detail yang mungkin tidak terlalu relevan.(tasks/threads) yang berjalan seolah-olah paralel.
- Sinkronisasi: Penggunaan Semaphore dan Mutex untuk mencegah race condition saat beberapa thread mengakses sumber daya yang sama.
- Penjadwalan Prioritas (Priority Scheduling): Memastikan tugas dengan prioritas tinggi (kritis) dieksekusi tepat waktu sesuai batasan real-time.
- Direct Memory Access (DMA): Fitur perangkat keras yang memungkinkan transfer data memori-ke-periferal (atau sebaliknya) tanpa membebani CPU, sangat vital untuk antarmuka high-speed.

# ANALISA KORELASI PROJECT DENGAN MATA KULIAH

## III.1 Arsitektur Mikrokontroler dan Hubungannya dengan Sistem

### III.1.1 Sistem Arsitektur ESP32 dan ESP 8266

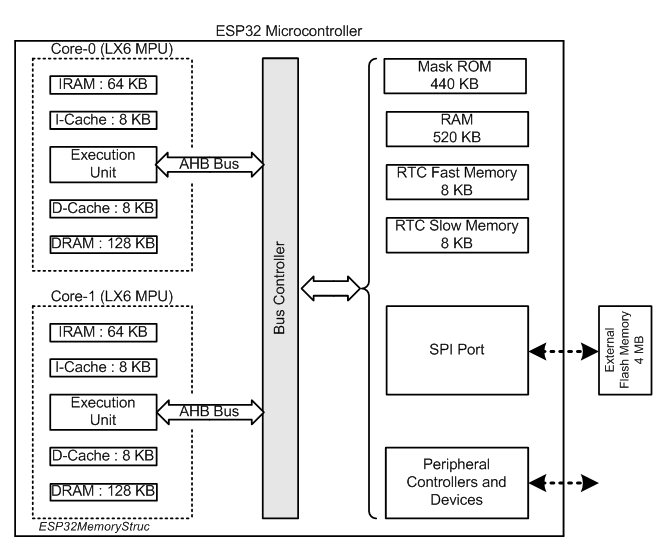
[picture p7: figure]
Learning Architecture and Multi-tasking Programming of 32-bit Dual-core Microcontroller using ESP32 Dev Module, Arduino IDE, ESP-IDF, and FreeRTOS - Education - Arduino Forum

Gambar 3 diagram sistem arsitektur ESP32

Dalam diagram arsitektur di gambar 3,ESP32 mengadopsi arsitektur Symmetric Multiprocessing (SMP) yang menawarkan kinerja tinggi melalui penggunaan dua unit pemrosesan identik berbasis Xtensa LX6. Dalam implementasi sistemnya, terdapat pembagian tugas yang efisien di mana Core-0 (dikenal sebagai Protocol CPU) umumnya dialokasikan untuk menangani stack komunikasi kritis seperti Wi-Fi dan Bluetooth, sedangkan Core-1 (Application CPU) didedikasikan penuh untuk mengeksekusi kode program pengguna. Keandalan kinerja dual-core ini didukung oleh struktur memori yang terdesentralisasi; setiap inti dilengkapi dengan sumber daya memori privat—mencakup IRAM 64 KB, I-Cache 8 KB, D-Cache 8 KB, dan DRAM 128 KB—yang berfungsi vital untuk meminimalkan terjadinya konflik akses memori (memory contention) antar-inti. Untuk mengintegrasikan seluruh komponen tersebut, sebuah Bus Controller sentral bertugas menghubungkan kedua inti prosesor dengan memori utama dan periferal melalui jalur Advanced High-performance Bus (AHB), sebuah mekanisme yang menjamin efisiensi transfer data dan akses instruksi secara simultan.

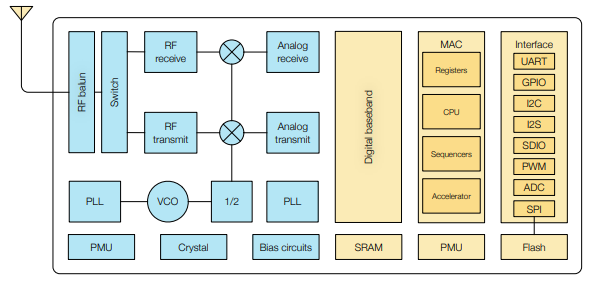
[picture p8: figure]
Introduction to the Internet of Things (IoT): ESP8266 architecture and Arduino GUI

Gambar 4 diagram sistem arsitektur ESP8266

Berdasarkan diagram blok fungsional pada Gambar 4, ESP8266 merupakan System-on-Chip (SoC) yang dirancang dengan tingkat integrasi tinggi. Arsitekturnya menekankan keseimbangan antara kemampuan pemrosesan aplikasi ringan dan penanganan stack protokol jaringan. Inti pemrosesannya menggunakan unit CPU 32-bit RISC bertipe Tensilica Xtensa L106, yang menerapkan pipeline lima tahap untuk meningkatkan efisiensi eksekusi instruksi. Selain itu, arsitektur ini mengintegrasikan sepenuhnya modul radio frekuensi (RF) seperti balun, penguat daya, penguat sinyal rendah, dan switch. Integrasi ini mengharuskan prosesor utama untuk mengatur waktu pemrosesannya secara bersama dengan lapisan basisband digital dan MAC guna menjaga stabilitas koneksi Wi-Fi. Dari sisi manajemen memori, ESP8266 tidak menyediakan flash internal untuk penyimpanan kode pengguna, kecuali memori ROM untuk proses boot. Kode program dieksekusi dari memori flash eksternal yang terhubung melalui antarmuka SPI, kemudian dimuat ke dalam Instruction RAM (IRAM) dengan memanfaatkan mekanisme cache.

ESP8266 dan ESP32 memiliki arsitektur register yang didasarkan pada desain RISC. Register merupakan penyimpanan berkecepatan tinggi yang terletak langsung di dalam CPU, dengan file register yang cukup besar (biasanya 32 atau 64 register untuk tujuan umum). Salah satu keunggulan utama arsitektur Xtensa yang digunakan pada kedua mikrokontroler ini adalah penggunaan windowed register file. Fitur ini memungkinkan rotasi register saat pemanggilan fungsi, sehingga mengurangi kebutuhan untuk menyimpan dan memulihkan data ke stack RAM yang lebih lambat. Hal ini meningkatkan efisiensi pemrosesan, terutama dalam penanganan rutin layanan interupsi (ISR) yang kompleks.

Bagian penting lain dari CPU adalah Arithmetic Logic Unit (ALU) dan, pada ESP32, Floating Point Unit (FPU). ALU menangani operasi aritmatika dan logika dasar. Pada ESP8266, operasi bilangan pecahan (floating point) harus disimulasikan secara perangkat lunak, yang memerlukan banyak siklus CPU. Namun, ESP32 dilengkapi dengan FPU perangkat keras yang memungkinkan pemrosesan algoritma kompleks seperti transformasi Fourier cepat (FFT) untuk analisis sinyal secara real-time tanpa membebani CPU secara berlebihan.

Unit kontrol berperan dalam mengatur eksekusi instruksi dan mengelola aliran data di dalam pipeline CPU. Pipeline pada prosesor ini umumnya terdiri dari lima tahap, yang memungkinkan eksekusi instruksi yang lebih efisien. Unit kontrol juga mencakup mekanisme prediksi cabang (branch prediction) untuk menjaga pipeline tetap terisi, meskipun prediksi yang salah dapat menyebabkan pengosongan pipeline dan penurunan kinerja sementara.

Komunikasi internal di dalam sistem dikelola melalui arsitektur bus berjenjang. ESP32 menggunakan dua jenis bus utama: AHB (Advanced High-performance Bus) untuk menghubungkan CPU dengan memori dan periferal berkecepatan tinggi seperti DMA, serta APB (Advanced Peripheral Bus) untuk periferal standar seperti UART, GPIO, dan timer. Pemisahan ini mencegah periferal yang lebih lambat menghambat akses CPU ke memori utama.

Selain komponen inti, mikrokontroler ini dilengkapi dengan berbagai periferal khusus. Salah satunya adalah Analog-to-Digital Converter (ADC) yang menggunakan arsitektur SAR (Successive Approximation Register) untuk mengubah sinyal analog menjadi digital dengan algoritma pencarian biner. Pada ESP32, ADC dapat bekerja bersama DMA untuk mengambil sampel secara otomatis tanpa intervensi CPU secara terus-menerus. ADC sering digunakan dalam sistem untuk membaca tegangan, misalnya dari tacho generator, dengan resolusi yang dapat diatur.

Periferal lain yang penting adalah Pulse Width Modulation (PWM), yang dihasilkan oleh kombinasi timer dan komparator perangkat keras. ESP32 memiliki modul PWM khusus seperti MCPWM dan LEDC untuk pengendalian mosfet . Dengan PWM perangkat keras, sinyal dapat dihasilkan secara stabil tanpa membebani CPU, sehingga cocok untuk aplikasi seperti penggerak motor DC melalui MOSFET.

Timer dan watchdog juga merupakan komponen. Timer digunakan untuk menghasilkan interupsi pada interval tertentu, misalnya untuk pengambilan data sensor atau eksekusi rutin PID. Watchdog timer berfungsi sebagai mekanisme keamanan yang akan melakukan reset sistem jika perangkat lunak macet dan gagal mereset timer tersebut dalam waktu yang ditentukan, memastikan keandalan sistem secara keseluruhan.

Terdapat juga komunikasi yang digunakan antar perangkat esp yaitu menggunakan ESP-NOW yang bekerja langsung di lapisan MAC (Media Access Control) Wi-Fi, bukan di atas protokol TCP/IP yang memerlukan koneksi terlebih dahulu. Ini berarti komunikasi terjadi hampir secara hardware-driven, dengan minimal keterlibatan CPU dan stack protokol tinggi.

Ketika dua ESP dikonfigurasi sebagai pasangan ESP-NOW, mereka saling bertukar kunci enkripsi dan alamat MAC. Setelah terpasang, data dari aplikasi dikirimkan langsung ke Wi-Fi Controller pada SoC melalui antarmuka perangkat lunak khusus. Kontroller Wi-Fi ini — yang memiliki prosesor dan memori sendiri — kemudian mengemas data menjadi frame MAC khusus ESP-NOW dan mengirimkannya secara broadcast atau unicast ke alamat MAC tujuan. Karena melewati TCP/IP, latensi menjadi sangat rendah (biasanya di bawah 10ms) dan overhead pemrosesan di CPU utama berkurang drastis, menghemat siklus clock untuk tugas aplikasi.
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

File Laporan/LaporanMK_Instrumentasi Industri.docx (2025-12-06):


Laporan Project Based Learning Mata Kuliah

VE230311 – Instrumentasi Industri

Semester Ganjil 2025/2026

SISTEM KONTROL SEDERHANA

Eskalator Mini Motor DC dengan Kendali ESP32 menggunakan Kontrol PID

Disusun oleh:

Abednego Tegar Imanto

NRP 2040241099

Program Studi Sarjana Terapan Teknologi Rekayasa Otomasi

Departemen Teknik Elektro Otomasi

Fakultas Vokasi

Institut Teknologi Sepuluh Nopember

Desember 2025

DAFTAR ISI

# RINGKASAN

Tujuan utama dari penyusunan laporan ini adalah untuk memahami secara mendalam korelasi antara mata kuliah Instrumentasi Industri dengan bentuk pembelajaran Project-Based Learning (PjBL), khususnya project pembuatan sistem kontrol kecepatan motor menggunakan metode PID yang diberikan kepada mahasiswa semester 3. Melalui PjBL, mahasiswa diharapkan tidak hanya memperoleh pemahaman dari sisi teori yang disampaikan di kelas, tetapi juga mampu menerapkan konsep-konsep tersebut dalam praktik nyata melalui kegiatan perancangan dan implementasi sistem kontrol.

Dengan melakukan analisis terhadap hubungan antara materi perkuliahan dan project yang dikerjakan, mahasiswa dapat melihat lebih jelas bagaimana konsep yang dipelajari memiliki peran penting dalam penyelesaian permasalahan teknis dalam pengerjaan project. Selain itu, kegiatan ini juga bertujuan untuk meningkatkan pemahaman mahasiswa mengenai fungsi dan manfaat setiap topik dalam mata kuliah Instrumentasi Industri, sehingga mereka mampu mengaitkan teori yang diperoleh dengan aplikasi praktis dalam bidang kontrol dan instrumentasi. Melalui proses tersebut, mahasiswa dapat mengembangkan kompetensi teknis, pemecahan masalah, serta keterampilan analitis yang diperlukan dalam dunia industri.

Kata Kunci: Instrumentasi Industri, PjBL, Kontrol PID

PENDAHULUAN

## I.1 Deskripsi Project

Proyek ini disusun dalam Penugasan Project Based Learning (PjBL), dengan tujuan mengintegrasikan teori yang telah dipelajari ke dalam sebuah implementasi yang nyata. Model pembelajaran ini mendorong mahasiswa untuk tidak hanya memahami konsep, tetapi juga mampu mengaplikasikannya dalam bentuk sistem yang dapat diuji dan dianalisis secara langsung.

Dalam hal ini, proyek yang dipilih adalah pembuatan eskalator mini berbasis kontrol PID dengan minimum system mikrokontroler ESP32 sebagai pengendali utama. Penggunaan kontrol PID penting karena mampu memberikan respons yang lebih stabil, presisi, dan Responsif terhadap perubahan beban maupun kecepatan pada sistem. Dengan demikian, eskalator mini dapat beroperasi secara lebih realistis dan menyerupai karakteristik sistem industri yang sebenarnya.

Mata kuliah yang mendukung pelaksanaan Project-Based Learning Sistem Kontrol Sederhana adalah:

1. VE230309 Mesin Listrik dan Kontrol Gerak
2. VE230310 Mikroprosesor dan Sistem Embedded
3. VE230311 Instrumentasi Industri
4. VE230312 Proyek 1: Desain Sistem Kontrol

Dengan keterkaitan ini, mahasiswa tidak hanya mengembangkan kemampuan teknis dalam perancangan sistem kontrol dan integrasi perangkat keras, tetapi juga membangun keterampilan analitis dan kolaboratif sesuai dengan tujuan PjBL.

## I.2 Target dan Cakupan Project

Mahasiswa mampu merancang keseluruhan sistem yang minimal harus terdiri atas:

1. Perangkat keras kontroler: Sistem Minimum Mikrokontroler ESP32

2. Metode Kontrol yang diimplementasikan pada program mikrokontroler (PID)

3. Sensor

4. Modul Input/Output untuk menghubungkan dari modul kontroler ke plant

5. Plant Motor DC dan Driver dengan tambahan plant berupa:

6. Plant Motor AC dan Inverter/VFD (disediakan oleh departemen)

7. 3D Desain Plant

MATERI MATA KULIAH INSTRUMENTASI INDUSTRI

## II.1 Deskripsi Mata Kuliah

Pada mata kuliah ini, mahasiswa akan mendapatkan pembelajaran tentang konsep sensor dan aktuator dengan pemahaman antarmuka dengan perangkat lain. Selain itu, diberikan juga pembelajaran tentang pengkondisi sinyal dan pendahuluan penggambaran P & ID,

## II.2 Materi Perkuliahan

### II.2.1 Pendahuluan Instrumentasi Industri

#### 1. Review Besaran dan Satuan

#### 2. Karakteristik Statik Pengukuran (Akurasi, Presisi, dll) dan kalibrasi

#### 3. Standar-standar pada Instrumentasi – Sinyal Transmisi

### II.2.2 Sensor & Pengkondisi Sinyal

#### 1. Instrumentasi Elektrik dan Pengkondisi Sinyal, ADC-DAC

#### 2. Pengukuran Proses (Temperature, Level, Pressure, Flow)
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

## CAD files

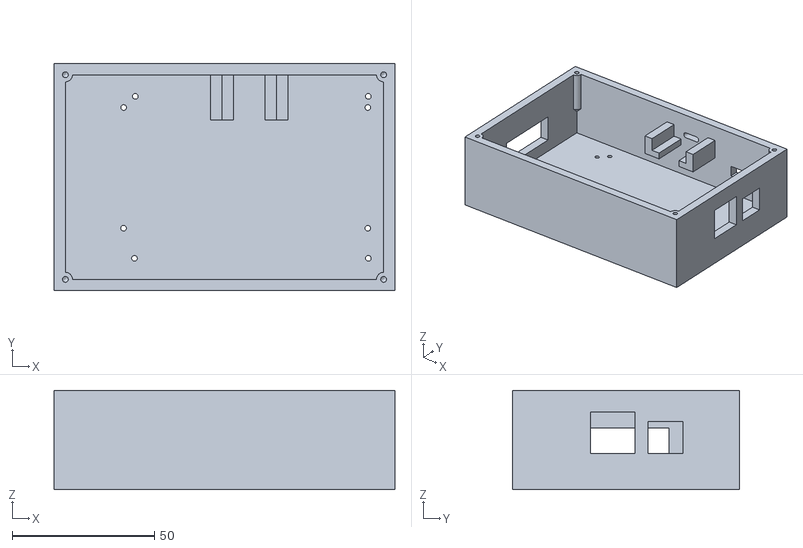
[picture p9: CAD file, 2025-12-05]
Design_3D/Box/Box_Bottom.stl
120.0 x 80.1 x 35.0

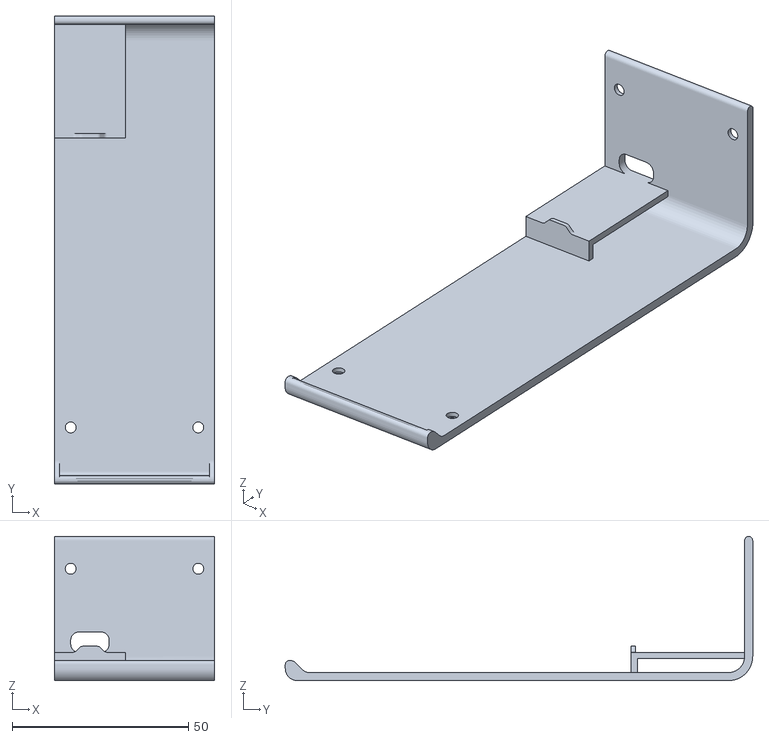
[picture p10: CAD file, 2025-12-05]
Design_3D/Eskalator/20x 10,4 Cm_bottom cover.stl
45.4 x 132.5 x 40.9

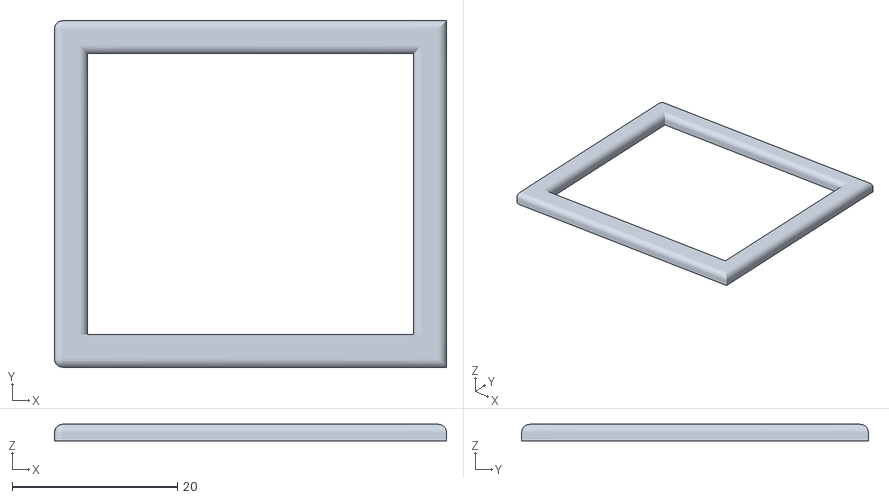
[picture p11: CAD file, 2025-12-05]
Design_3D/Interface/Cover_LCD.stl
47.5 x 42.0 x 2.00

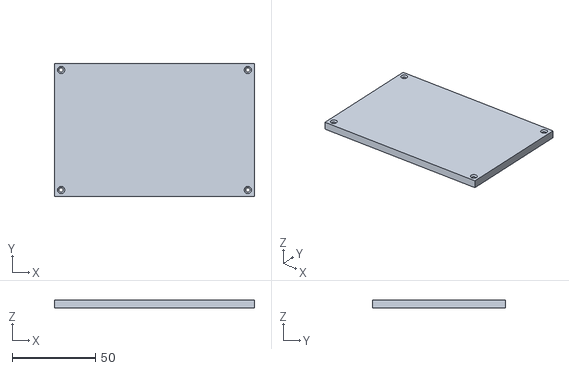
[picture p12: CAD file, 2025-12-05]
Design_3D/Box/Box_Top.stl
120.0 x 80.0 x 5.00

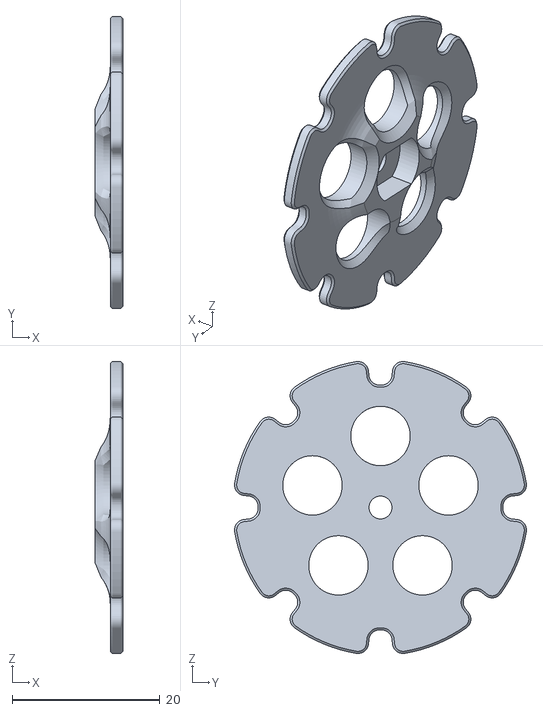
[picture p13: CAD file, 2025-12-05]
Design_3D/Eskalator/20x 10,4 Cm_drive side sprocket.stl
3.79 x 39.5 x 39.5

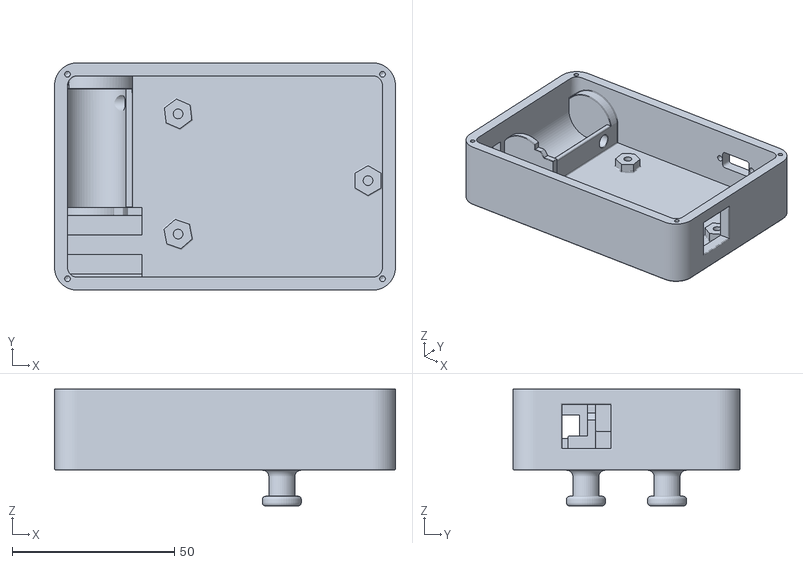
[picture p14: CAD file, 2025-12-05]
Design_3D/Interface/Box_Interface_Bottom.stl
105.0 x 70.0 x 36.0

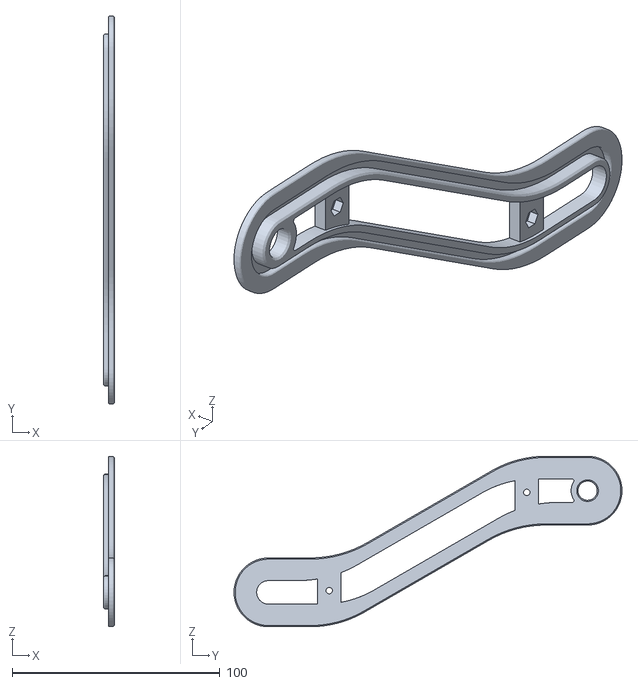
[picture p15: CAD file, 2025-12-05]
Design_3D/Eskalator/20x 10,4 Cm_track guide_Right.stl
5.17 x 186.8 x 82.1

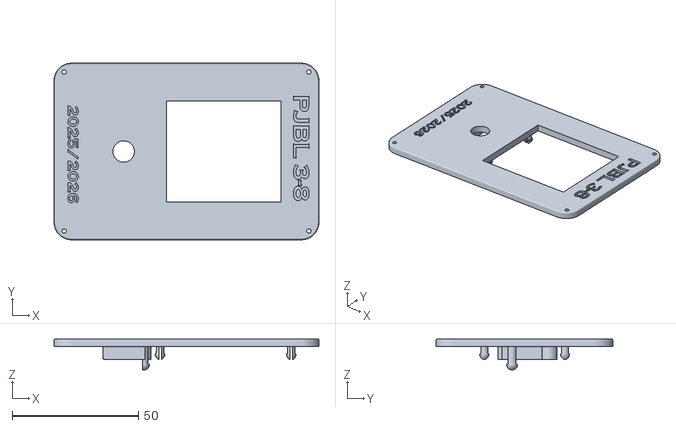
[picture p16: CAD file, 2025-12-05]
Design_3D/Interface/Box_Interface_Top.stl
105.0 x 70.0 x 12.3

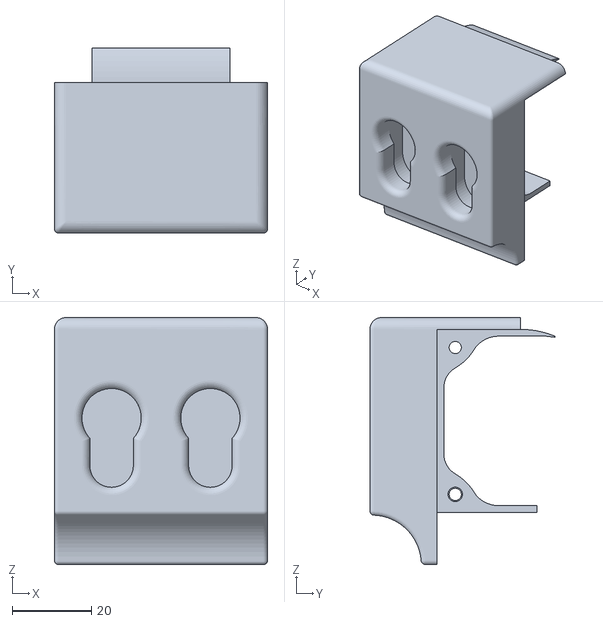
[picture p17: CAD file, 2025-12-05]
Design_3D/Eskalator/20x 10,4 Cm_end plate_Back.stl
54.0 x 46.9 x 62.5

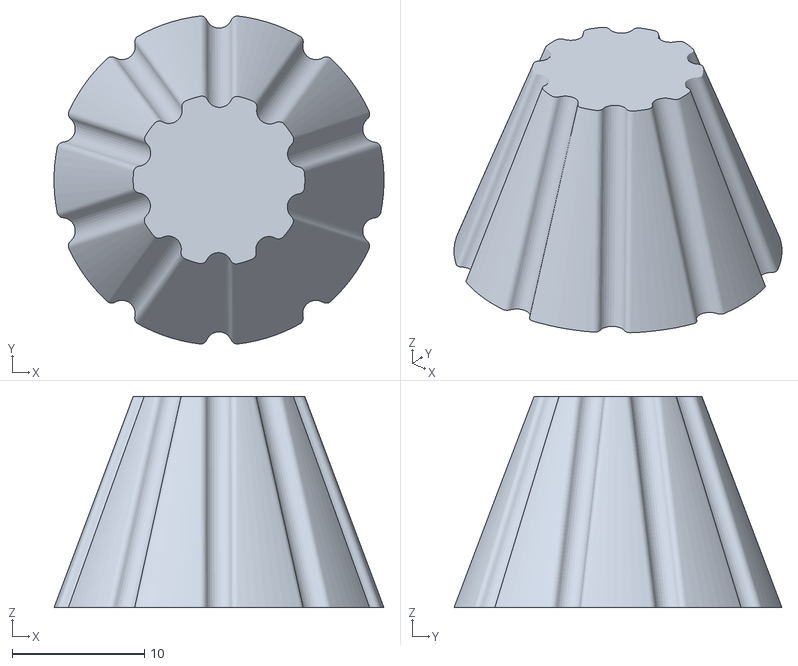
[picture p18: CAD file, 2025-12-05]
Design_3D/Interface/Knob_Interface.stl
25.0 x 24.8 x 16.0

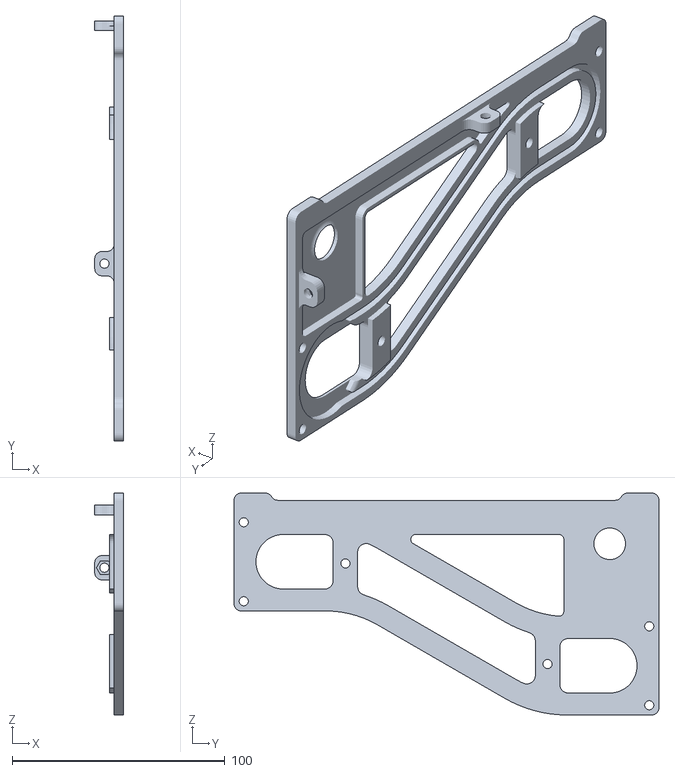
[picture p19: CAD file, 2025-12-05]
Design_3D/Eskalator/20x 10,4 Cm_left outer guide.stl
13.5 x 200.0 x 104.5

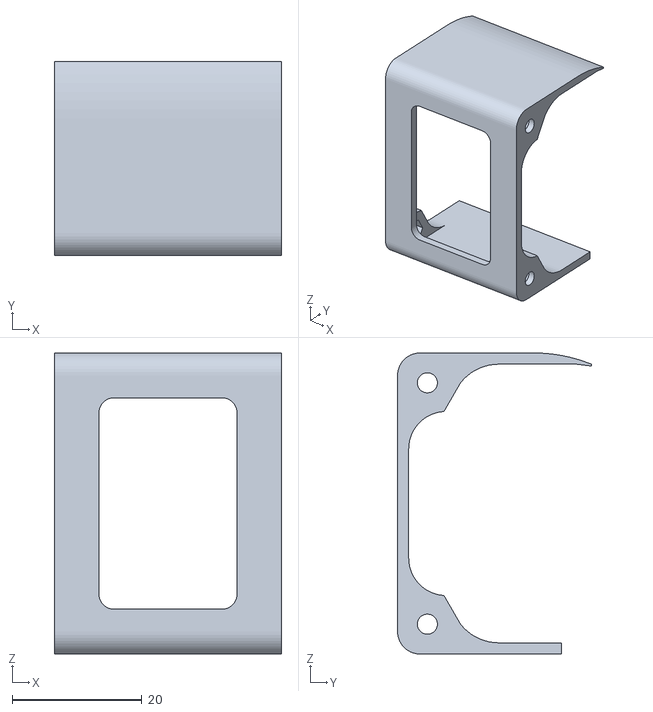
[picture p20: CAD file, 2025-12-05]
Design_3D/Eskalator/20x 10,4 Cm_end plate_Front.stl
35.0 x 29.9 x 46.3

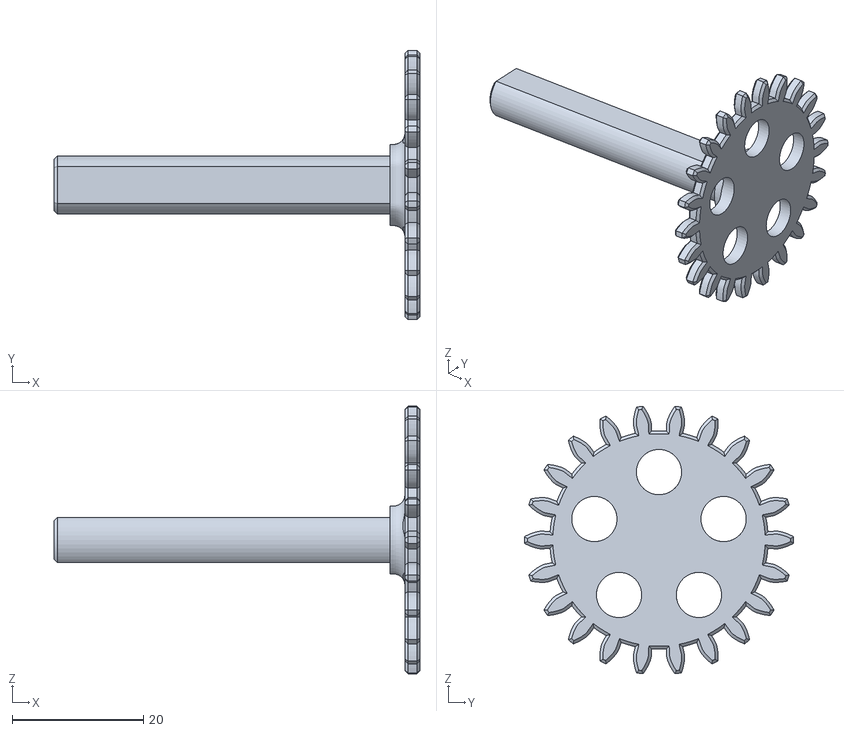
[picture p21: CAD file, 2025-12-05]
Design_3D/Eskalator/20x 10,4 Cm_sprocket shaft.stl
55.7 x 41.0 x 40.7

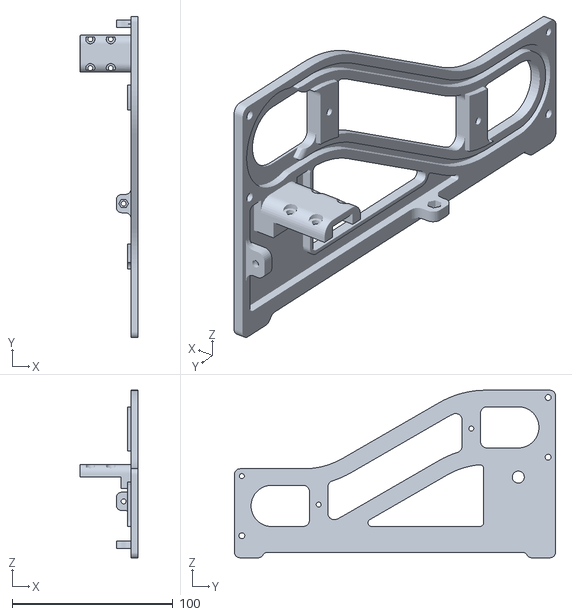
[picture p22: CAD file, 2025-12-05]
Design_3D/Eskalator/20x 10,4 Cm_right outer guide.stl
36.0 x 200.0 x 104.5

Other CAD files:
Design_3D/Eskalator/20x 10,4 Cm_track guide_Left.stl
Design_3D/Eskalator/20x 10,4 Cm_chain link.stl
Design_3D/Eskalator/20x 10,4 Cm_handrail mid guide_Left.stl
Design_3D/Eskalator/20x 10,4 Cm_non drive side sprocket.stl
Design_3D/Eskalator/20x 10,4 Cm_Motor Clamp.stl
Design_3D/Eskalator/20x 10,4 Cm_handrail mid guide_Right.stl
Design_3D/Eskalator/20x 10,4 Cm_motor pinion.stl
Design_3D/Interface/washer.stl

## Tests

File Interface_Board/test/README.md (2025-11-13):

# Encoder Test Program

## Cara Menggunakan:

### 1. Backup main.cpp yang asli
```bash
# Rename file main.cpp yang ada
mv src/src/main.cpp src/src/main_backup.cpp
```

### 2. Copy encoder_test.cpp ke main.cpp
```bash
cp test/encoder_test.cpp src/src/main.cpp
```

### 3. Upload ke board
```bash
platformio run --target upload
```

### 4. Monitor Serial Output
```bash
platformio device monitor
```

### 5. Test Encoder
- Putar encoder perlahan searah jarum jam -> harus muncul "+" dan Position naik
- Putar encoder perlahan berlawanan jarum jam -> harus muncul "-" dan Position turun
- Tekan tombol encoder -> Position reset ke 0

### 6. Yang Harus Diperhatikan:

**Normal Behavior:**
- Setiap detik encoder = 1 perubahan position (±1)
- Symbol +/- muncul konsisten dengan arah putaran
- Trigger rate sekitar 2-4 Hz untuk putaran lambat
- Pin states berubah antara 0 dan 1

**Abnormal Behavior (masalah):**
- Position loncat 2-3 dalam 1 detik
- Symbol +/- muncul bersamaan atau random
- Trigger rate > 20 Hz saat diam
- Pin states selalu sama (0 atau 1)

### 7. Kembalikan ke program normal
```bash
# Restore original main.cpp
mv src/src/main_backup.cpp src/src/main.cpp
platformio run --target upload
```

## Output Example:

```
========================================
ENCODER DEBUG & LOGGING TEST
========================================
CLK Pin: 25
DT Pin: 26
SW Pin: 27
========================================
Rotate encoder to test...
Press button to reset position
+ = Clockwise, - = Counter-clockwise
========================================

Ready! Start rotating encoder...

++
----------------------------------------
Time: 1234 ms
Position: 2 (Change: +2)
Total Triggers: 45
Trigger Rate: 36.5 Hz
Pin States: CLK=1, DT=0, SW=1
----------------------------------------
```

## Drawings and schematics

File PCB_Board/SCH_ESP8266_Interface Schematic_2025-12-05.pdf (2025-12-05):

USB | VOLTAGE REGULATOR

# BOOT & ENABLE

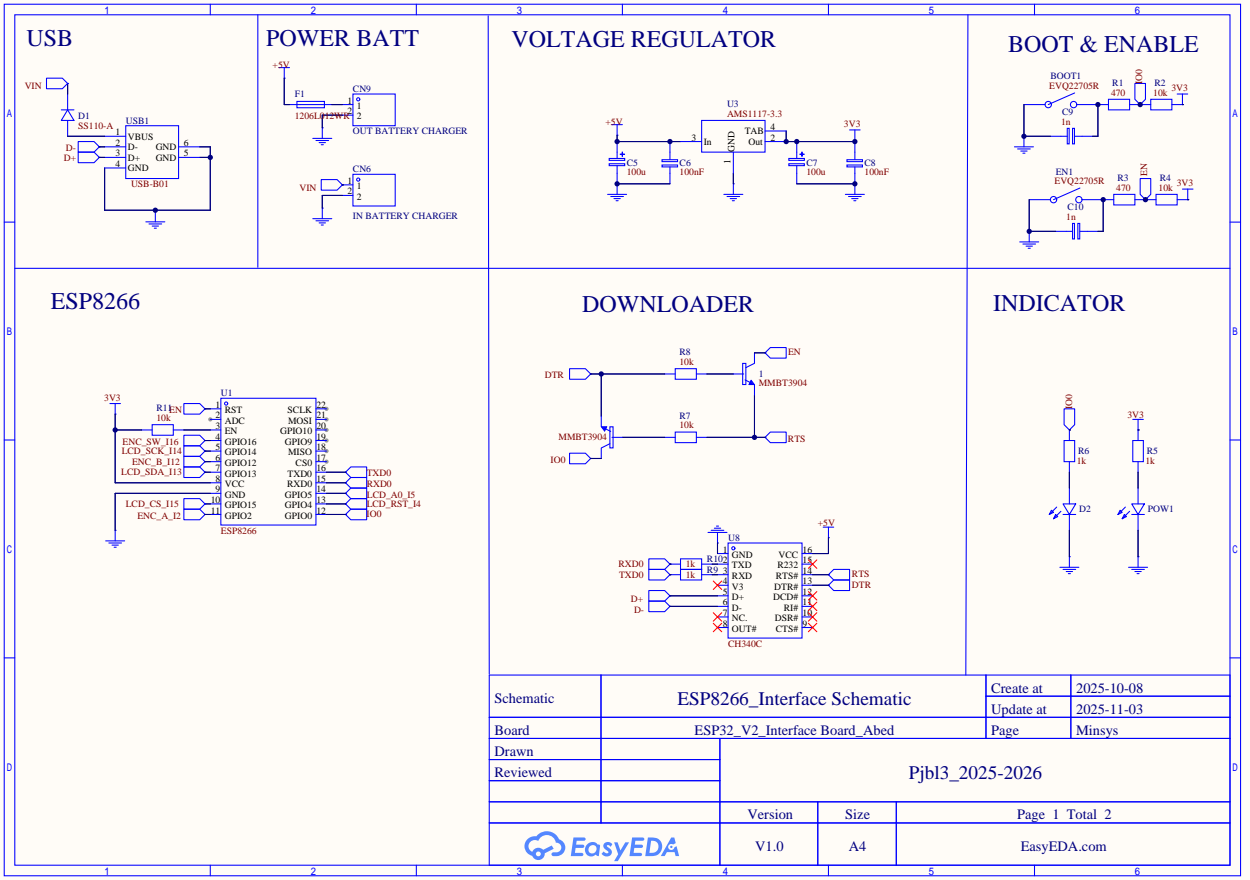
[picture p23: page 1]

DSR# 10 RI# 11 DCD# 12 DTR# 13 RTS# 14 R232 15 VCC 16

Schematic | ESP8266_Interface Schematic | Create at | 2025-10-08

Update at | 2025-11-03

Board | ESP32_V2_Interface Board_Abed | Page | Minsys
Drawn | | Pjbl3_2025-2026
Reviewed

Version | Size | Page 1 Total 2

V1.0 | A4 | EasyEDA.com

Connector LCD | Encoder Pull Up | Connector Encoder Interface

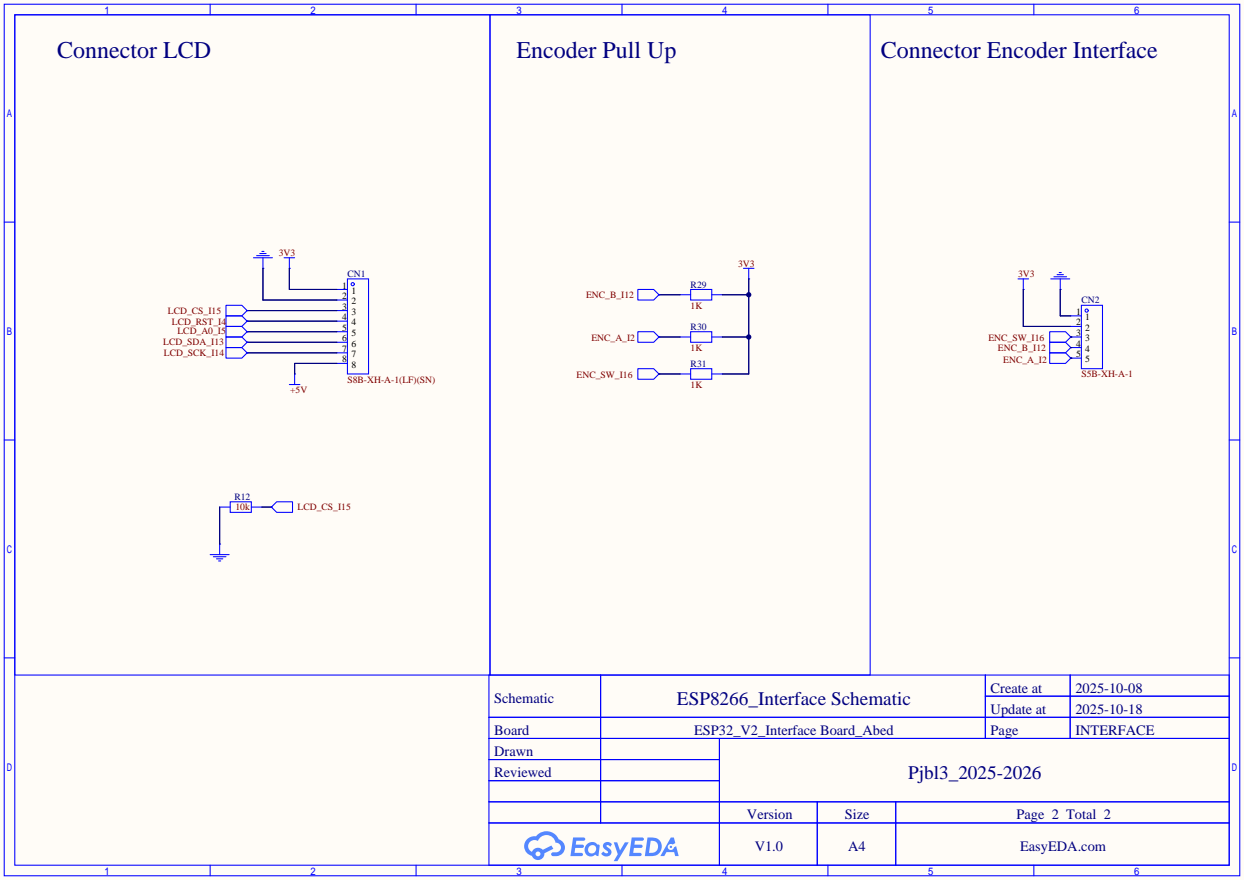
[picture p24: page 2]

Schematic | ESP8266_Interface Schematic | Create at | 2025-10-08

Update at | 2025-10-18

Board | ESP32_V2_Interface Board_Abed | Page | INTERFACE
Drawn | | Pjbl3_2025-2026
Reviewed

Version | Size | Page 2 Total 2

V1.0 | A4 | EasyEDA.com

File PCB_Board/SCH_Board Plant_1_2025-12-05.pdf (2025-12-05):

USB | VOLTAGE REGULATOR

# BOOT & ENABLE

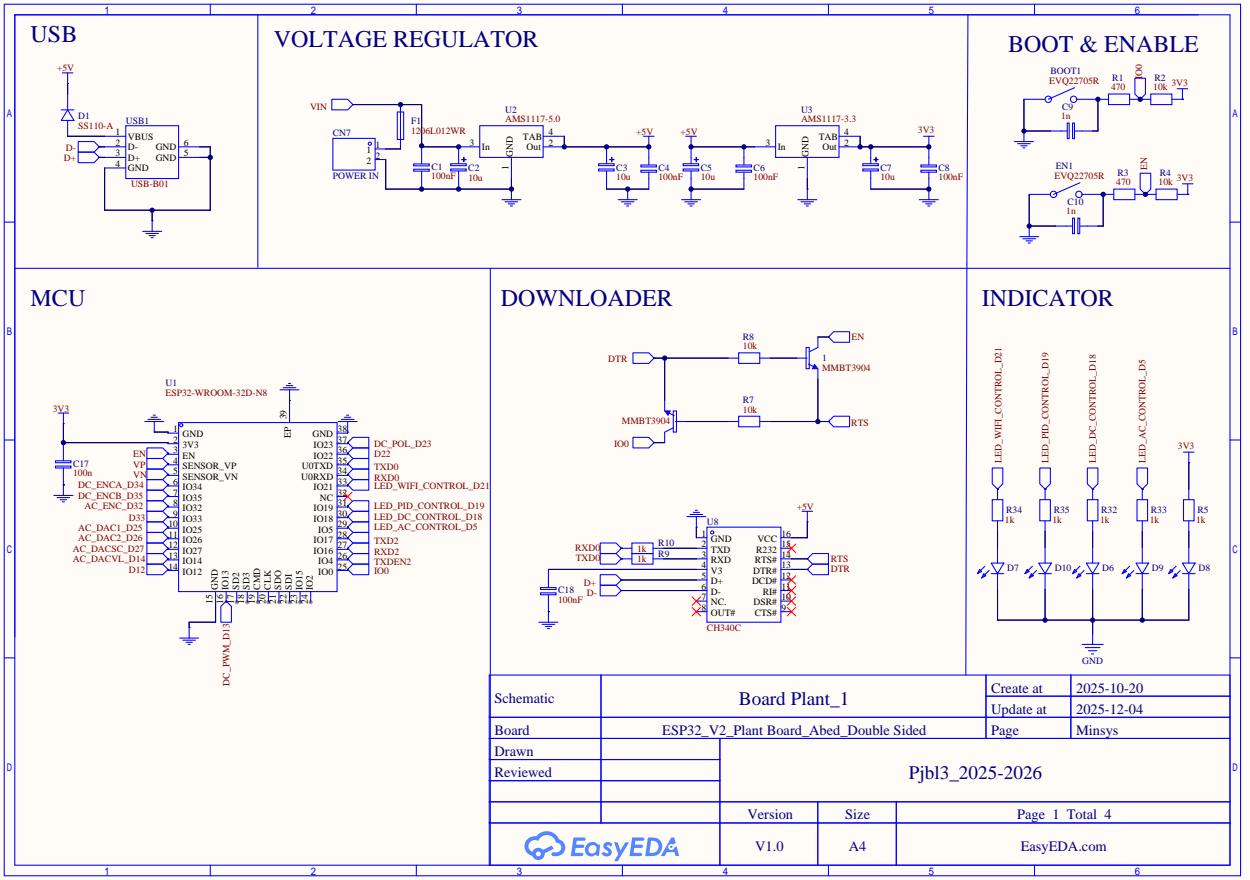
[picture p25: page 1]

DSR# 10 RI# 11 DCD# 12 DTR# 13 RTS# 14 R232 15 VCC 16

Schematic | Board Plant_1 | Create at | 2025-10-20

Update at | 2025-12-04

Board | ESP32_V2_Plant Board_Abed_Double Sided | Page | Minsys
Drawn | | Pjbl3_2025-2026
Reviewed

Version | Size | Page 1 Total 4

V1.0 | A4 | EasyEDA.com

Relay Driver | Encoder Pull Up | DC Motor Conector

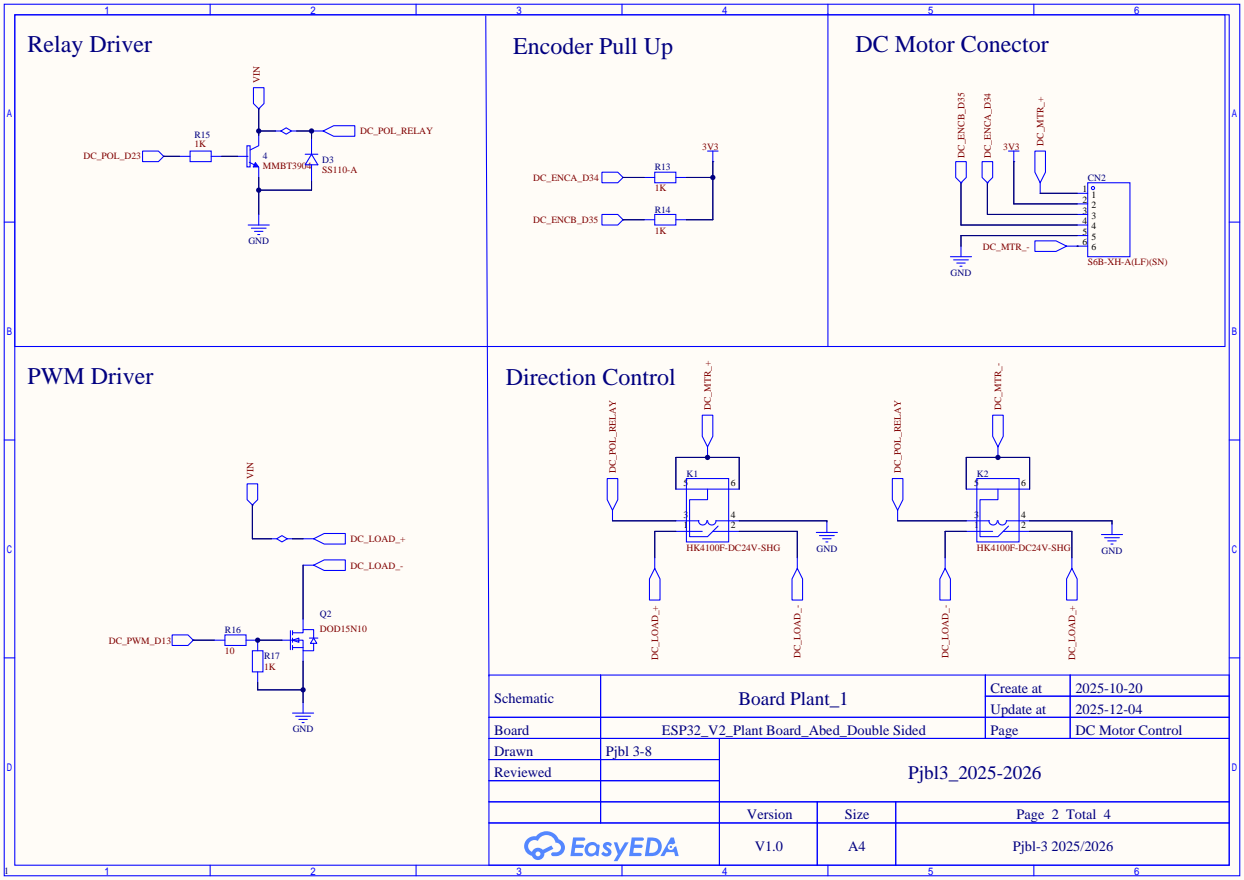
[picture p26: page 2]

Schematic | Board Plant_1 | Create at | 2025-10-20

Update at | 2025-12-04

Board | ESP32_V2_Plant Board_Abed_Double Sided | Page | DC Motor Control
Drawn | Pjbl 3-8 | Pjbl3_2025-2026
Reviewed

Version | Size | Page 2 Total 4

V1.0 | A4 | Pjbl-3 2025/2026

5V to 3.3V Level Converter | AC Motor Encoder & DAC Connector

# PWM TO ANALOG

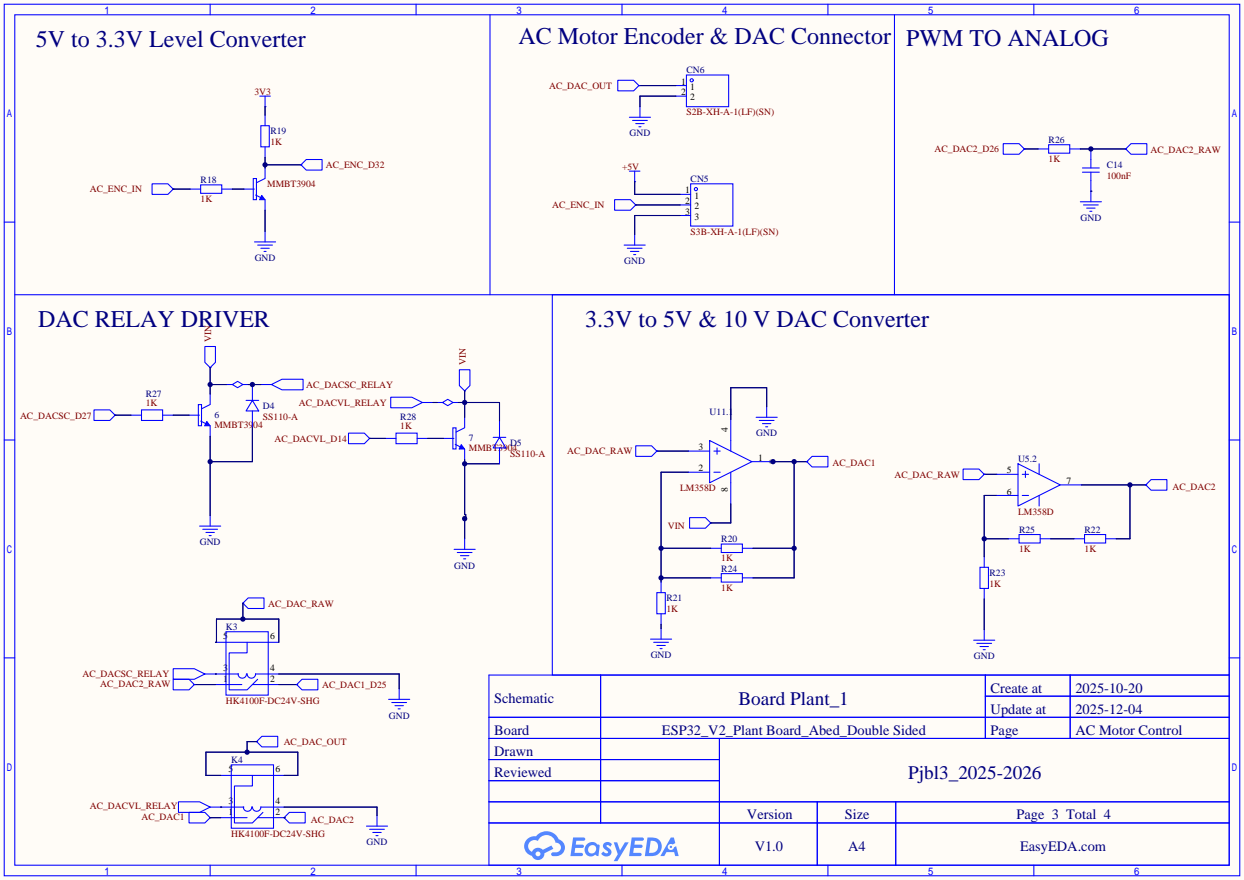
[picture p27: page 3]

Schematic | Board Plant_1 | Create at | 2025-10-20

Update at | 2025-12-04

Board | ESP32_V2_Plant Board_Abed_Double Sided | Page | AC Motor Control
Drawn | | Pjbl3_2025-2026
Reviewed

TTL to RS485 | Ethernet connector

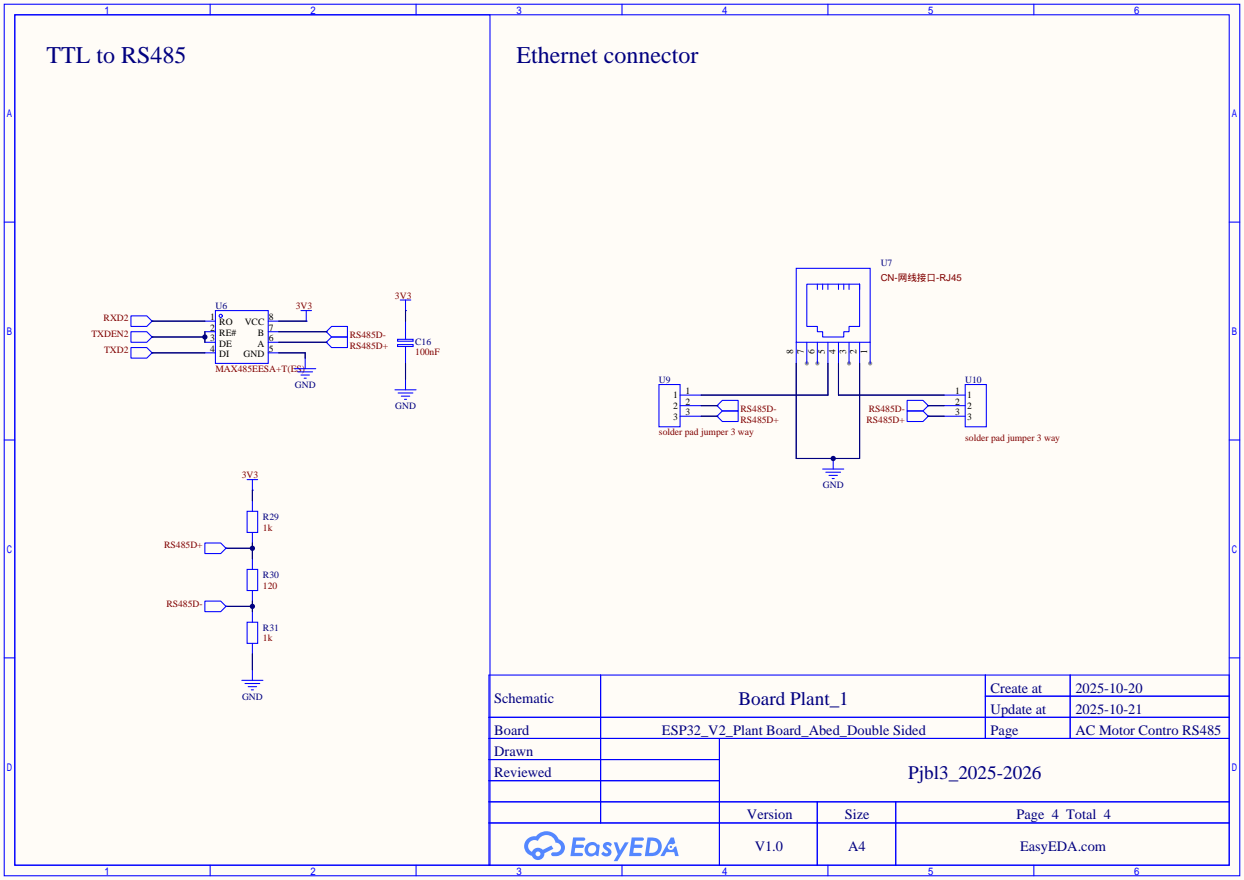
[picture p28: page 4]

solder pad jumper 3 way

Schematic | Board Plant_1 | Create at | 2025-10-20

Update at | 2025-10-21

Board | ESP32_V2_Plant Board_Abed_Double Sided | Page | AC Motor Contro RS485
Drawn | | Pjbl3_2025-2026
Reviewed

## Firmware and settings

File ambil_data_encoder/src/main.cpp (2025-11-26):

#include <Arduino.h>
#include <PlantConfig.h>

volatile long encoder = 0;
volatile long lastEncoder = 0;
volatile float rpm = 0;
volatile long pulseCount = 0;
volatile bool dataready = false;
hw_timer_t *m_timer = NULL;
bool flip = false;
// Variables for speed and direction control
int motorSpeed = 125;       // Default speed (0-255)
bool motorDirection = HIGH; // Default direction

void IRAM_ATTR onTimer() {
  digitalWrite(LED_WIFI, !digitalRead(LED_WIFI));
  pulseCount = encoder - lastEncoder;
  lastEncoder = encoder;
  rpm =
      (pulseCount * (60000.0 / DCREAD_INTERVAL)) / PPR; // pembacaan tiap 10 ms
  dataready = true;
}

void IRAM_ATTR handleEncodera_rising() {
  // Serial.print("ISR A Rising called\n");
  int stateA = digitalRead(ENCODER_A_PIN);
  int stateB = digitalRead(ENCODER_B_PIN);

  if (stateA == HIGH && stateB == LOW) {
    encoder++;
  } else if (stateA == HIGH && stateB == HIGH) {
    encoder--;
  }
}
void IRAM_ATTR handleEncoderb_rising() {
  // Serial.print("ISR B Rising called\n");
  int stateA = digitalRead(ENCODER_A_PIN);
  int stateB = digitalRead(ENCODER_B_PIN);

  if (stateA == HIGH && stateB == HIGH) {
    encoder++;
  } else if (stateA == LOW && stateB == HIGH) {
    encoder--;
  }
}

void IRAM_ATTR handleEncodera_falling() {
  // Serial.print("ISR A Falling called\n");
  int stateA = digitalRead(ENCODER_A_PIN);
  int stateB = digitalRead(ENCODER_B_PIN);

  if (stateA == LOW && stateB == HIGH) {
    encoder++;
  } else if (stateA == LOW && stateB == LOW) {
    encoder--;
  }
}
void IRAM_ATTR handleEncoderb_falling() {
  // Serial.print("ISR B Falling called\n");
  int stateA = digitalRead(ENCODER_A_PIN);
  int stateB = digitalRead(ENCODER_B_PIN);

  if (stateA == LOW && stateB == LOW) {
    encoder++;
  } else if (stateA == HIGH && stateB == LOW) {
    encoder--;
  }
}

void acsweep() {
  for (int x = 0; x <= 255; x++) {
    Serial.print("DAC Value: ");
    Serial.println(x);

    if (x < 1) {
      dacDisable(AC_DAC1_PIN);
      pinMode(AC_DAC1_PIN, OUTPUT);

      digitalWrite(AC_DAC1_PIN, LOW);
      delay(5000);
    } else if (x > 254) {
      dacDisable(AC_DAC1_PIN);
      pinMode(AC_DAC1_PIN, OUTPUT);

      digitalWrite(AC_DAC1_PIN, HIGH);
      delay(5000);
    } else {
      dacWrite(AC_DAC1_PIN, x);
      delay(10);
    }
  }
  Serial.println("AC sweep complete");
}

void setup() {
  pinMode(LED_WIFI, OUTPUT);
  pinMode(LED_PID, OUTPUT);
  pinMode(LED_DC_CONTROL, OUTPUT);
  pinMode(LED_AC_CONTROL, OUTPUT);
  pinMode(LED_STATUS, OUTPUT);
  pinMode(LED_ESPNOW, OUTPUT);
  pinMode(ENCODER_A_PIN, INPUT);
  pinMode(ENCODER_B_PIN, INPUT);
  pinMode(MOTOR_DIR_PIN, OUTPUT);
  digitalWrite(MOTOR_DIR_PIN, motorDirection);
  m_timer = timerBegin(0, 80, true); // Timer 0, prescaler 80, count up
  timerAlarmWrite(m_timer, DCREAD_INTERVAL * 1000,
                  true); // 10 ms alarm, autoreload true
  timerAttachInterrupt(m_timer, &onTimer, true);
  timerAlarmEnable(m_timer); // Enable the alarm

  attachInterrupt(digitalPinToInterrupt(ENCODER_A_PIN),handleEncodera_rising,RISING);
  // attachInterrupt(digitalPinToInterrupt(ENCODER_B_PIN),handleEncoderb_rising,RISING);
  // attachInterrupt(digitalPinToInterrupt(ENCODER_A_PIN),handleEncodera_falling,FALLING);
  // attachInterrupt(digitalPinToInterrupt(ENCODER_B_PIN), handleEncoderb_falling,FALLING);

  ledcSetup(PWM_CHANNEL, PWM_FREQ, PWM_RESOLUTION);
  ledcAttachPin(MOTOR_PWM_PIN, PWM_CHANNEL);
  ledcWrite(PWM_CHANNEL, motorSpeed); // speed 0 - 255

  Serial.begin(115200);
  Serial.println("Motor Control Ready!");
  Serial.println("Commands:");
  Serial.println("  s<value> - Set speed (0-255), e.g., s150");
  Serial.println("  d<value> - Set direction (0 or 1), e.g., d1");
  pinMode(AC_DAC1_PIN, OUTPUT);
  pinMode(AC_DAC_SOURCE_PIN, OUTPUT);
  pinMode(AC_DAC_VOLTAGE_SELECT_PIN, OUTPUT);
  digitalWrite(AC_DAC_SOURCE_PIN, LOW);
  digitalWrite(AC_DAC_VOLTAGE_SELECT_PIN, HIGH);
}

void loop() {
  // // acsweep();
  // // delay(1000);
  // // float analogValue = analogRead(AC_ENCODER_PIN);
  // // Serial.println(analogValue);
  // if (Serial.available() > 0) {
  //   String input = Serial.readStringUntil('\n');
  //   input.trim();

  //   if (input.length() > 0) {
  //     char command = input.charAt(0);
  //     int value = input.substring(1).toInt();

  //     if (command == 's' || command == 'S') {
  //       // Set speed
  //       if (value >= 0 && value <= 255) {
  //         motorSpeed = value;
  //         ledcWrite(PWM_CHANNEL, motorSpeed);
  //         Serial.print("Speed set to: ");
  //         Serial.println(motorSpeed);
  //       } else {
  //         Serial.println("Error: Speed must be 0-255");
  //       }
  //     } else if (command == 'd' || command == 'D') {
  //       // Set direction
  //       if (value == 0 || value == 1) {
  //         motorDirection = (value == 1) ? HIGH : LOW;
  //         digitalWrite(MOTOR_DIR_PIN, motorDirection);
  //         Serial.print("Direction set to: ");
  //         Serial.println(motorDirection == HIGH ? "HIGH (1)" : "LOW (0)");
  //       } else {
  //         Serial.println("Error: Direction must be 0 or 1");
  //       }
  //     } else {
  //       Serial.println("Unknown command. Use s<value> for speed or d<value> "
  //                      "for direction");
  //     }
  //   }
  // }

  if (dataready) {
    if (digitalRead(MOTOR_DIR_PIN) == HIGH) {
      Serial.print("Direction: HIGH , ");
    } else {
      Serial.print("Direction: LOW , ");
    }
    Serial.print(encoder);
    Serial.print(" , ");
    Serial.print(pulseCount);
    Serial.print(" , ");
    Serial.println(rpm);
    dataready = false;
  }

  static unsigned long lastSend = 0;
  if (millis() - lastSend > 10000) { // Send every 10 seconds
    lastSend = millis();
    flip = !flip;
    if (!flip) {
      digitalWrite(MOTOR_DIR_PIN, !digitalRead(MOTOR_DIR_PIN));
      delay(100);
    }
  }
  if (flip) {
    ledcWrite(PWM_CHANNEL, 0);
  } else {
    if (!flip) {
      ledcWrite(PWM_CHANNEL, 250);
    }
  }
  
}

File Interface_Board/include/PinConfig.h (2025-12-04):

#ifndef PIN_CONFIG_H
#define PIN_CONFIG_H

// Ensure fixed-width integer types like uint8_t are available
#include <Arduino.h>

// ========================================
// KONFIGURASI PIN - ESP32 & ESP8266 Compatible
// File ini berisi deklarasi semua pin yang digunakan
// ========================================

#ifdef ESP32
// ========================================
// ESP32 PIN CONFIGURATION
// ========================================

// LCD ST7735 Pins (SPI)
#define TFT_CS 15 // Chip select
#define TFT_RST 4 // Reset
#define TFT_DC 5  // Data/Command
// SPI pins (hardware): MOSI=23, SCK=18

// Rotary Encoder Pins
#define ENCODER_CLK 27 // CLK_PIN / Channel A
#define ENCODER_DT 26  // DT_PIN / Channel B
#define ENCODER_SW 25  // SW_PIN / Switch button

// Motor Driver Pins
#define MOTOR_IN1 12 // Motor input 1
#define MOTOR_IN2 14 // Motor input 2

// LED Status Pin
#define LED_STATUS 13 // LED status

// Pin untuk Sensor (optional)
#define SENSOR_TEMP_PIN 35
#define SENSOR_LDR_PIN 36

// Pin untuk Motor (optional)
#define MOTOR1_PIN_A 12
#define MOTOR1_PIN_B 13
#define MOTOR2_PIN_A 14
#define MOTOR2_PIN_B 15

#elif defined(ESP8266)
// ========================================
// ESP8266 PIN CONFIGURATION
// ========================================

// LCD ST7735 Pins (SPI)
#define TFT_CS 15              // GPIO15 - Chip select
#define TFT_RST 4              // GPIO4 - Reset
#define TFT_DC 5               // GPIO5 - Data/Command
// SPI pins (hardware): MOSI=GPIO13, SCK=GPIO14

// Rotary Encoder Pins
#define ENCODER_CLK 12         // GPIO12 - CLK_PIN / Channel A
#define ENCODER_DT 2           // GPIO2 - DT_PIN / Channel B
#define ENCODER_SW 16          // GPIO16 - SW_PIN / Switch button

// Motor Driver Pins
#define MOTOR_IN1 12           // GPIO12 - Motor input 1
#define MOTOR_IN2 13           // GPIO13 - Motor input 2

// LED Status Pin
#define LED_STATUS LED_BUILTIN // Built-in LED (GPIO2)

// Pin untuk Sensor (optional)
#define SENSOR_TEMP_PIN A0     // Analog pin
#define SENSOR_LDR_PIN A0      // Analog pin (shared)

// Pin untuk Motor (optional)
#define MOTOR1_PIN_A 12        // GPIO12
#define MOTOR1_PIN_B 13        // GPIO13
#define MOTOR2_PIN_A 14        // GPIO14
#define MOTOR2_PIN_B 15        // GPIO15

#endif

// ========================================
// COMMON CONSTANTS
// ========================================

#define PWM_FREQ 5000
#define PWM_RESOLUTION 8
#define SERIAL_BAUD 115200

// ========================================
// NETWORK CONFIGURATION
// ========================================

// WiFi AP Configuration
#define WIFI_AP_SSID "GameBoard_AP"
#define WIFI_AP_PASSWORD "12345678"

// ESP-NOW Configuration
// MAC Address untuk komunikasi (sesuaikan dengan device kalian)
// SignBox/Plant MAC Address
static const uint8_t PLANT_MAC[6] = {0x7C, 0x9E, 0xBD, 0x48, 0x85, 0xB4};

// Contoh MAC Address lainnya (uncomment jika diperlukan)

#endif // PIN_CONFIG_H

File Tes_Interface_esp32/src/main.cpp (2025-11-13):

// ========================================
// CONTOH PENGGUNAAN CONTROL MENU SYSTEM
// Rename file ini menjadi main.cpp untuk menggunakannya
// ========================================

#include <Adafruit_GFX.h>
#include <Adafruit_ST7735.h>
#include <Arduino.h>
#include <SPI.h>
#include <WiFi.h>
#include <esp_now.h>

#include "ControlMenuSystem.h"
#include "EncoderControl.h"
#include "NetworkManager.h"
#include "PinConfig.h"

// ========================================
// GLOBAL OBJECTS
// ========================================

Adafruit_ST7735 tft = Adafruit_ST7735(TFT_CS, TFT_DC, TFT_RST);
ControlMenuSystem menuSystem(&tft);
EncoderControl encoder(ENCODER_CLK, ENCODER_DT, ENCODER_SW);
NetworkManager network;

// ========================================
// NETWORK CALLBACKS - Data dari PLANT
// ========================================

void onPlantDataReceived(EscalatorDataPacket data) {
  // Update data ke menu system
  Direction dir = (data.direction == 0) ? DIR_FORWARD : DIR_REVERSE;
  menuSystem.updateEscalatorData(data.currentSpeed, dir);

  // Log data yang diterima
  Serial.println("\n[PLANT DATA]");
  Serial.printf("  Speed: %.2f RPM\n", data.currentSpeed);
  Serial.printf("  Direction: %s\n", data.direction == 0 ? "FWD" : "REV");
  Serial.printf("  Mode: %s\n", data.mode == 0 ? "MANUAL" : "AUTO");
  Serial.printf("  Running: %s\n", data.isRunning ? "YES" : "NO");
}

void onMotorDataReceived(MotorACDataPacket data) {
  // Update data ke menu system
  menuSystem.updateMotorACData(data.currentSpeed);

  // Log data yang diterima
  Serial.println("\n[MOTOR DATA]");
  Serial.printf("  Speed: %.2f RPM\n", data.currentSpeed);
  Serial.printf("  Mode: %s\n", data.mode == 0 ? "MANUAL" : "AUTO");
  Serial.printf("  Running: %s\n", data.isRunning ? "YES" : "NO");
}

void onNetworkSendComplete(const uint8_t *mac, bool success) {
  if (success) {
    Serial.println("[SEND] Command sent successfully");
  } else {
    Serial.println("[SEND] Command failed to send");
  }
}

// ========================================
// ENCODER CALLBACKS
// ========================================

void onEncoderRotate(int direction) {
  menuSystem.navigate(direction);
  // LED feedback saat navigasi
  digitalWrite(LED_STATUS, HIGH);
  delay(10);
  digitalWrite(LED_STATUS, LOW);
}

void onEncoderClick() { menuSystem.select(); }

void onEncoderLongPress() { menuSystem.back(); }

// ========================================
// SETUP & LOOP
// ========================================

void setup() {
  Serial.begin(SERIAL_BAUD);
  delay(1000);

  Serial.println("\n========================================");
  Serial.println("Control Interface v2.0");
  Serial.println("========================================");

  // Init LCD PERTAMA (sebelum pin lain)
  Serial.println("[LCD] Initializing display...");

  // Reset display
  pinMode(TFT_RST, OUTPUT);
  digitalWrite(TFT_RST, HIGH);
  delay(10);
  digitalWrite(TFT_RST, LOW);
  delay(10);
  digitalWrite(TFT_RST, HIGH);
  delay(150);

  // Init SPI dan LCD
  SPI.begin();
  tft.initR(INITR_BLACKTAB);
  tft.setRotation(0); // 0 = portrait (vertical)
  tft.fillScreen(ST77XX_BLACK);

  Serial.println("[LCD] Display initialized");

  // Test LCD - tampilkan teks sederhana
  tft.setTextColor(ST77XX_WHITE);
  tft.setTextSize(1);
  tft.setCursor(10, 10);
  tft.println("Initializing...");

  delay(500);

  // Init LED Status (sekarang sudah aman, tidak bentrok)
  pinMode(LED_STATUS, OUTPUT);
  digitalWrite(LED_STATUS, LOW);

  // Init Menu
  Serial.println("[MENU] Initializing menu system...");
  menuSystem.begin();

  // Init Encoder
  encoder.begin();
  encoder.onRotate(onEncoderRotate);
  encoder.onClick(onEncoderClick);
  encoder.onLongPress(onEncoderLongPress);

  // Init Network Manager
  Serial.println("\n[NETWORK] Initializing...");

  // Init WiFi AP Mode
  if (network.beginWiFiAP(WIFI_AP_SSID, WIFI_AP_PASSWORD)) {
    String ipAddr = network.getAPIP();
    menuSystem.updateNetworkStatus(true, WIFI_AP_SSID, ipAddr,
                                   network.getConnectedClients());
  }

  // Init ESP-NOW
  if (network.beginESPNow()) {
    menuSystem.updateESPNowStatus(true, 0);

    // Set Plant MAC Address dari PinConfig.h
    uint8_t plantMac[] = PLANT_MAC;
    network.setEscalatorMAC(plantMac);

    // Add Plant sebagai peer
    if (network.addEscalatorPeer()) {
      Serial.println("[NETWORK] Plant peer added");
      menuSystem.updateESPNowStatus(true, 1);
    }

    // Set callbacks untuk menerima data
    network.onReceiveEscalatorData(onPlantDataReceived);
    network.onReceiveMotorACData(onMotorDataReceived);
    network.onSendComplete(onNetworkSendComplete);
  }

  // Print network status
  network.printStatus();

  Serial.println("\n[SYSTEM] Setup Complete!");
  Serial.println("=========================================\n");
}
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

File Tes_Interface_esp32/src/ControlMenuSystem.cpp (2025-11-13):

#include "ControlMenuSystem.h"

// ========================================
// CONSTRUCTOR
// ========================================

ControlMenuSystem::ControlMenuSystem(Adafruit_ST7735 *tft) {
  display = tft;
  currentMenu = MENU_ROOT;
  selectedIndex = 0;
  isEditing = false;

  lastGraphUpdate = 0;
  graphUpdateInterval = 100; // Update grafik setiap 100ms

  // Initialize data structures
  escalatorData = {};
  escalatorData.currentSpeed = 0;
  escalatorData.targetSpeed = 0;
  escalatorData.direction = DIR_FORWARD;
  escalatorData.mode = MODE_MANUAL;
  escalatorData.pid = {1.0, 0.1, 0.05, 50.0, 0};
  escalatorData.isConnected = false;
  escalatorData.historyIndex = 0;

  motorACData = {};
  motorACData.currentSpeed = 0;
  motorACData.targetSpeed = 0;
  motorACData.mode = MODE_MANUAL;
  motorACData.controlType = CTRL_DAC;
  motorACData.voltageType = VOLTAGE_10V;
  motorACData.pid = {2.0, 0.5, 0.1, 1000.0, 0};
  motorACData.isConnected = false;
  motorACData.historyIndex = 0;

  networkStatus = {};
  networkStatus.wifiConnected = false;
  networkStatus.espnowInitialized = false;

  // Define colors
  COLOR_BG = display->color565(0, 0, 20);
  COLOR_HEADER = display->color565(0, 80, 160);
  COLOR_SELECTED = display->color565(50, 150, 255);
  COLOR_EDITING = display->color565(255, 100, 0);
  COLOR_TEXT = display->color565(255, 255, 255);
  COLOR_ACCENT = display->color565(255, 200, 0);
  COLOR_SUCCESS = display->color565(0, 255, 0);
  COLOR_ERROR = display->color565(255, 0, 0);
  COLOR_WARNING = display->color565(255, 150, 0);
  COLOR_GRAPH_GRID = display->color565(40, 40, 60);
  COLOR_GRAPH_LINE = display->color565(0, 255, 200);
}

// ========================================
// INITIALIZATION
// ========================================

void ControlMenuSystem::begin() {
  display->fillScreen(COLOR_BG);
  showSplashScreen();
  delay(2000);
  drawRootMenu();
}

void ControlMenuSystem::showSplashScreen() {
  display->fillScreen(ST77XX_BLACK);

  // Title
  display->setTextColor(COLOR_ACCENT);
  display->setTextSize(2);
  display->setCursor(getCenterX("Control", 2), 50);
  display->println("Control");
  display->setCursor(getCenterX("System", 2), 70);
  display->println("System");

  // Subtitle
  display->setTextColor(COLOR_TEXT);
  display->setTextSize(1);
  display->setCursor(getCenterX("Escalator"), 100);
  display->println("Escalator");
  display->setCursor(getCenterX("& Motor"), 112);
  display->println("& Motor");

  // Version
  display->setTextColor(COLOR_ACCENT);
  display->setCursor(getCenterX("v2.0"), 135);
  display->println("v2.0");

  // Loading bar (vertical layout)
  int barWidth = 90;
  int barX = (128 - barWidth) / 2;
  int barY = 150;
  display->drawRect(barX, barY, barWidth, 6, COLOR_HEADER);

  for (int i = 0; i < barWidth - 2; i += 4) {
    display->fillRect(barX + 1, barY + 1, i, 4, COLOR_SUCCESS);
    delay(35);
  }
}

// ========================================
// HELPER FUNCTIONS
// ========================================

int ControlMenuSystem::getCenterX(const char *text, int textSize) {
  int16_t x1, y1;
  uint16_t w, h;
  display->setTextSize(textSize);
  display->getTextBounds(text, 0, 0, &x1, &y1, &w, &h);
  return (128 - w) / 2;
}

void ControlMenuSystem::drawHeader(const char *title, bool showBackIcon) {
  display->fillRect(0, 0, 128, 18, COLOR_HEADER);

  // Back icon
  if (showBackIcon && currentMenu != MENU_ROOT) {
    display->fillTriangle(5, 9, 10, 5, 10, 13, COLOR_TEXT);
  }

  // Title (centered)
  display->setTextColor(ST77XX_WHITE);
  display->setTextSize(1);
  display->setCursor(getCenterX(title), 5);
  display->println(title);
}

void ControlMenuSystem::drawFooter(const char *text) {
  display->fillRect(0, 142, 128, 18, COLOR_HEADER);
  display->setTextColor(ST77XX_WHITE);
  display->setTextSize(1);
  // Wrap text untuk vertical display
  display->setCursor(2, 145);

  // Potong text jika terlalu panjang (max ~21 karakter untuk width 128)
  String str = String(text);
  if (str.length() > 21) {
    str = str.substring(0, 18) + "...";
  }
  display->println(str);
}

void ControlMenuSystem::drawMenuItem(int y, const char *text, bool selected,
                                     bool hasSubmenu) {
  if (selected) {
    display->fillRoundRect(3, y, 122, 16, 3,
                           isEditing ? COLOR_EDITING : COLOR_SELECTED);
    display->setTextColor(ST77XX_BLACK);
  } else {
    display->drawRoundRect(3, y, 122, 16, 3, COLOR_TEXT);
    display->setTextColor(COLOR_TEXT);
  }

  display->setTextSize(1);
  display->setCursor(8, y + 4);
  display->println(text);

  // Arrow untuk submenu
  if (hasSubmenu) {
    display->fillTriangle(115, y + 8, 119, y + 5, 119, y + 11,
                          selected ? ST77XX_BLACK : COLOR_ACCENT);
  }
}

void ControlMenuSystem::drawValueBar(int x, int y, int w, int h, float value,
                                     float maxVal, uint16_t color) {
  display->drawRect(x, y, w, h, COLOR_TEXT);
  int fillWidth = (int)((value / maxVal) * (w - 2));
  fillWidth = constrain(fillWidth, 0, w - 2);
  display->fillRect(x + 1, y + 1, fillWidth, h - 2, color);
}

void ControlMenuSystem::drawGraph(int x, int y, int w, int h, float *data,
                                  int dataSize, float maxVal) {
  // Draw frame
  display->drawRect(x, y, w, h, COLOR_TEXT);

  // Draw grid lines (horizontal)
  for (int i = 1; i < 4; i++) {
    int gridY = y + (h * i) / 4;
    for (int gx = x + 2; gx < x + w - 2; gx += 3) {
      display->drawPixel(gx, gridY, COLOR_GRAPH_GRID);
    }
  }

  // Draw data points
  for (int i = 1; i < dataSize && i < w - 2; i++) {
    float val1 = data[i - 1];
    float val2 = data[i];

    int y1 = y + h - 2 - (int)((val1 / maxVal) * (h - 4));
    int y2 = y + h - 2 - (int)((val2 / maxVal) * (h - 4));

    y1 = constrain(y1, y + 1, y + h - 2);
    y2 = constrain(y2, y + 1, y + h - 2);

    display->drawLine(x + i, y1, x + i + 1, y2, COLOR_GRAPH_LINE);
  }
}

void ControlMenuSystem::drawStatusIndicator(int x, int y, bool connected) {
  if (connected) {
    display->fillCircle(x, y, 3, COLOR_SUCCESS);
  } else {
    display->fillCircle(x, y, 3, COLOR_ERROR);
  }
}
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

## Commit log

2025-11-13 Add NetworkManager and main application for control interface
    - Implement NetworkManager class for managing WiFi and ESP-NOW communication.
    - Create main application to initialize display, menu system, and network.
    - Add callbacks for receiving data from escalator and motor AC.
    - Implement encoder control for user navigation in the menu.
    - Set up LED indicators for status feedback.
    - Include example files for network and control menu usage.
    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
2025-11-13 Add detailed README files for all project components, including Interface Board, Plant Board, testing procedures, and encoder data acquisition.
2025-11-17 Refactor encoder control and PID management; enhance data storage functionality and improve LED control timing
2025-11-20 Refactor PID control and ESP-NOW communication
    - Improved PID control logic in PID.cpp with anti-windup and output saturation adjustments.
    - Enhanced Plant.cpp to manage AC and DC motor control modes and integrate ESP-NOW for data transmission.
    - Streamlined PlantESPNow.cpp for better data handling and peer management in ESP-NOW.
    - Updated main.cpp to initialize components and load PID configurations.
    - Added ControlMenuSystem_simple.cpp for a user interface to manage escalator and motor settings.
    - Adjusted data handling in ambil_data_encoder to improve command processing and encoder data reading.
2025-11-22 Refactor and enhance control logic for DC and AC motors
    - Updated encoder handling in EncoderControl.cpp to simplify ISR logic.
    - Improved NetworkManager.cpp to handle new message types for DC and AC speed, PID parameters, and setpoints.
    - Modified main.cpp to incorporate new motor control logic based on menu interactions.
    - Changed PID.h and PID.cpp to use float instead of double for PID parameters and added a function to update PID parameters via ESP-NOW.
    - Enhanced DataStorage.cpp to reset NVS data and load PID values with safe defaults.
    - Adjusted Plant.h and PlantConfig.h to include new variables and constants for RPM calculations.
    - Updated PlantESPNow.cpp to manage ESP-NOW communicati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
    [ControlMenuSystem_simple.cpp, DataStorage.cpp, EncoderControl.cpp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]
2025-11-22 Refactor code structure for improved readability and maintainability
    [tes pembacaan serial.xlsx]
2025-11-26 Update motor control parameters and enhance PID functionality; adjust upload and monitor ports
    [Data Pengukuran monitor logging.xlsx]
2025-12-04 Add initial dataset for AC3 motor measurements in CSV format
    [Data Pengukuran monitor logging.xlsx, datapengukuran motor AC.csv, datapengukuran motor AC2.csv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]
2025-12-05 Refactor code structure and remove redundant code blocks for improved readability and maintainability
    [20x 10,4 Cm_Motor Clamp.stl, 20x 10,4 Cm_bottom cover.stl, 20x 10,4 Cm_chain link.stl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]
2025-12-06 Refactor Plant Board code and add operational documentation
    - Removed unnecessary whitespace in main.cpp.
    - Deleted temporary file ~WRL1495.tmp.
    - Added comprehensive operational flow documentation for the dual motor control system, detailing initialization, main loop operations, PID control, communication protocols, and user interaction scen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
2026-09-14 Add technical documentation archive (dokumen teknis.rar)
    [Motor AC.xlsx, Motor AC2.xlsx, data plant.xlsx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]
